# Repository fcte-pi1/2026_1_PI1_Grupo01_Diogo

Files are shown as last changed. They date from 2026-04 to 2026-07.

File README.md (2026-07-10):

# MrBombastic - Grupo 01

Repositório do projeto de um robô autônomo MicroMouse para a disciplina de Projeto Integrador 1 (PI1) da FCTE-UnB.

## Equipe

* **Arthur Guilherme Aquino** - Software
* **Arthur Luiz Silva Guedes** - Eletrônica
* **Enzo Macedo da Motta de Mello** - Estrutura
* **Felipe de Castro Quixabeira** - Eletrônica (Gerente)
* **Fernando de Melo Colli** - Energia (Gerente) e Eletrônica
* **João Igor Pereira da Costa** - Eletrônica e Software
* **Magno Luiz Vale Vieira** - Energia e Software
* **Maria Luisa Alves Rodrigues** - Eletrônica
* **Mariana Pereira Schumann** - Estrutura (Gerente)
* **Matheus de Alcantara da Silva Campos** - Software
* **Raphaela Guimarães de Araujo dos Santos** - Estrutura
* **Renan Pereira Reis** - Software (Gerente)
* **Ricardo Henrique Silva Rodrigues** - Software
* **Tiago Lemes Teixeira** - Gerente Geral
* **Vilmar Jose Fagundes dos Passos Junior** - Estrutura

## Estrutura de Pastas
* **`docs/relatorio/`**: Relatório técnico oficial (LaTeX).
* **`hw/`**: Hardware (esquemáticos e projetos de PCB).
* **`mec/`**: Mecânica (modelagem 3D e CAD).
* **`src/`**: Software (código-fonte e firmware).

---

## Padrões do Repositório

### 1. Nomenclatura de Branches
Padrão: `[ÁREA]_[NÚMERO_DA_ISSUE]-[descrição-curta]`
* **ES** - Estrutura
* **EL** - Eletrônica
* **EN** - Energia
* **SW** - Software
* *Exemplo:* `SW_12-algoritmo-mapeamento`

### 2. Mensagens de Commit
Inicie os commits com os seguintes prefixos:
* **[ADD]**: Criação de arquivos ou funcionalidades.
* **[FIX]**: Correção de bugs.
* **[DOCS]**: Atualização do relatório ou README.
* **[REF]**: Refatoração e organização de código.
* *Exemplo:* `[ADD] leitura dos sensores infravermelhos`

## Guia de Contribuição

### Tutorial: Fluxo Git (Terminal)
Siga este passo a passo para cada nova edição:
1. `git pull origin main` (Atualiza seu local)
2. `git checkout -b [NOME_DA_SUA_BRANCH]` (Cria sua ramificação)
3. Faça suas alterações.
4. `git add .`
5. `git commit -m "[PREFIXO] descrição curta"`
6. `git push origin [NOME_DA_SUA_BRANCH]`
7. Abra o **Pull Request** no site do GitHub.

### Tutorial: Relatório (Sincronização Overleaf)
Como o uso do Overleaf é manual, siga esta ordem:
1. No Overleaf, edite apenas os arquivos na pasta `editaveis/`.
2. Baixe os arquivos `.tex` alterados para sua máquina.
3. Substitua-os na pasta `docs/relatorio/editaveis/` do seu repositório local.
4. Siga o **Fluxo Git** acima para subir as mudanças.
*Observação: Não altere o `main.tex` nem envie arquivos `.pdf` no commit.*

# Como rodar o projeto?

## Rodando o Prisma na Aplicação
Como o Prisma já está configurado no projeto, utilize os comandos abaixo conforme a necessidade.

### 1. Instalar dependências (caso necessário)
```bash
npm install
```

### 2. Gerar o Prisma Client
Sempre que houver alterações no arquivo `schema.prisma`:
```bash
npx prisma generate
```

### 3. Criar uma migration
Após modificar o schema:
```bash
npx prisma migrate dev --name nome_da_migration
```

### 4. Aplicar migrations existentes
Caso esteja clonando o projeto ou atualizando o banco:
```bash
npx prisma migrate deploy
```

### 5. Sincronizar schema sem criar migration
Útil durante desenvolvimento:
```bash
npx prisma db push
```

### 6. Abrir o Prisma Studio
Interface visual para visualizar e editar dados:
```bash
npx prisma studio
```

```bash
npx prisma migrate dev
```
## Rodando o BackEnd
Acessar a pasta do projeto
```bash
cd src/backend
```
Instalar as dependências:
```bash
npm install
```
Executar a plaicação:
```bash
npm run dev
```

## Rodando o FrontEnd
Acessar a pasta do projeto
```bash
cd src/frontend
```
Instalar as dependências:
```bash
npm install
```
Executar a plaicação:
```bash
npm run dev
```

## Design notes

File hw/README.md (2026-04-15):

# _Hardware_

Esta pasta deverá armazenar arquivos referentes a:

- Simulações de circuitos eletrônicos (alimentação, sensores, atuadores etc.): [Qucs](https://qucs.sourceforge.net/), [QSPICE](https://www.qorvo.com/design-hub/design-tools/interactive/qspice), [Fritzing](https://fritzing.org/), dentre outros.
- Esquemáticos de circuitos: [KiCad](https://www.kicad.org/), Qucs, QSPICE.
- Diagramas de bloco: [Canva](https://www.canva.com/pt_br/), [TikZ](https://tikz.net/).
- _Datasheets_ de componentes eletrônicos, microcontroladores, _shields_ Arduino, motores etc.
- Testes tabelados de circuitos: arquivos CSV, Excel.
- Imagens PNG e JPEG de resultados práticos: fotos de testes reais, gráficos de resultados etc.
- Outros arquivos referentes ao _hardware_ do projeto.

> [!WARNING]
> **Não acrescente código-fonte a esta pasta.** O código desenvolvido para microcontroladores e SOCs ([Arduino](https://www.arduino.cc/), [ESP32](https://www.espressif.com/), [Raspberry Pi](https://www.raspberrypi.com/)) deverá ser armazenado na pasta [src/firmware](https://github.com/fcte-pi1/template/tree/main/src/firmware) deste repositório.

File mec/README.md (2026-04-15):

# _Mecânica e Estruturas_

Esta pasta deverá ser utilizada para armazenar arquivos relativos ao projeto estrutural, mecanismos, materiais, estudos aerodinâmicos, equações dinâmicas, construção e manufatura, impressão 3D, e correlatos.

Os arquivos a serem incluídos, são, dentre outros:
- Arquivos CAD de peças e montagens (FCStd, STEP, etc). 
- Desenhos técnicos (pdf, etc).
- Arquivos de impressão 3D (STL, etc).
- Imagens rasterizadas e vetorizadas (eps, pdf, svg, etc).
- Documentos e estudos realizados para o projeto (markdown, LaTeX, etc).

Durante o projeto, os grupos são encorajados a realizarem estudos para o projeto de estruturas, mecanismos, aerodinamica, dentre outros, e muitos desses estudos não caberão no relatório a ser entregue. Esses estudos podem ser colocados também nessa pasta, preferencialmente utilizando markdown (.md) para facilitar a leitura em ambiente web. Lembre-se que você pode utilizar equações em formato LaTeX no markdown e não deixe de utilizar links para o material de referencia que utilizaram. Estudos bem realizados contarão de maneira positiva na avaliação das equipes, porém lembre-se que não é permitida a utilização de IA, e que esse material deve ser principalmente útil à equipe.

> [!WARNING]
> Não acrecente arquivos da parte de hardware eletrônico aqui, como arquivos de KiCAD. Estes devem ser salvos na pasta [hw](https://github.com/fcte-pi1/template/tree/main/hw) deste repositório.

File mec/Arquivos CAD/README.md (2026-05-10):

# Arquivos CAD - MrBombastic

Esta pasta contém os arquivos CAD referentes ao projeto.

## Equipe

Os integrantes envolvidos na criação dos arquivos em CAD foram:

- **Enzo Macedo da Motta de Mello** 
- **Mariana Pereira Schumann**

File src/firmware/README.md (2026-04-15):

# _Firmware_
Esta pasta deverá armazenar arquivos referentes a:

- Código-fonte para microcontroladores e SOCs: [Arduino](https://www.arduino.cc/), [ESP32](https://www.espressif.com/), [Raspberry Pi](https://www.raspberrypi.com/), dentre outros.
- Projetos de organização destes códigos, caso utilize IDEs: [Arduino IDE](https://www.arduino.cc/en/software/), [Visual Studio](https://visualstudio.microsoft.com/pt-br/downloads/) etc.
- Arquivos de configuração: ```CMakeLists.txt``` se for usar [CMake](https://cmake.org/download/), ```Makefile``` se for usar [make](https://www.cs.colby.edu/maxwell/courses/tutorials/maketutor/) etc.

Evite incluir:
- Artefatos de compilação: os arquivos de saída compilados (binários, arquivos objeto, .hex, .elf) devem ser gerados pelo processo de compilação e não incluídos no repositório.
- Arquivos temporários/específicos do sistema operacional: Arquivos como .DS_Store (macOS) ou arquivos de configuração do editor (a menos que esteja usando uma configuração compartilhada como .editorconfig).
- Configurações pessoais: Arquivos de configuração locais específicos da máquina do desenvolvedor.

> [!WARNING]
> **Não acrescente arquivos referentes a _hardware_ nesta pasta.** Eles deverão ser armazenados na pasta [hw](https://github.com/fcte-pi1/template/tree/main/hw) deste repositório.

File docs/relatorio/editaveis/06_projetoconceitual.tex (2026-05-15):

\chapter{Projeto Conceitual do Produto}

\section{Características gerais}

O produto proposto é um robô autônomo de pequeno porte, denominado Micromouse, cujo objetivo
principal é explorar e resolver labirintos desconhecidos de forma completamente autônoma, sem
qualquer intervenção humana durante o percurso. O robô deverá ser capaz de mapear o ambiente,
monitorar sua própria localização, detectar paredes com $5{,}0\,\text{cm}$ de altura e
$1{,}2\,\text{cm}$ de espessura, e identificar quando alcançou a região central do labirinto,
que corresponde a uma sala retangular de aproximadamente $2 \times 2$ células.

O Micromouse será construído dentro das dimensões máximas de
$25{,}0\,\text{cm} \times 25{,}0\,\text{cm}$, sobre um \textit{chassis} com tração diferencial
de duas rodas motorizadas e uma roda de apoio livre. A navegação será realizada por meio de
três sensores de distância por tempo de voo (\textit{Time of Flight}) VL53L0X, posicionados
nas direções frontal e laterais, complementados por uma unidade de medição inercial MPU6050
responsável pela correção de trajetória nas curvas. O controle dos motores N20 será feito por
uma ponte H TB6612FNG, além disso, eles já apresentam encoder acoplados a cada motor.

O sistema embarcado será gerenciado por um microcontrolador ESP32 DevKitV1, responsável pela
execução do algoritmo de navegação, pelo mapeamento do labirinto em memória e pela comunicação
sem fio via Wi-Fi com a interface de telemetria. O produto contará com monitoramento em tempo
real de tensão e corrente por meio do módulo INA219, exibindo na tela de acompanhamento o tipo
do labirinto, o trajeto percorrido, a velocidade média, o consumo de bateria e o tempo de
conclusão. A alimentação será fornecida por duas células de lítio Lishen LR2170SA em
configuração $2S$, gerenciadas por um BMS 2S 20A com indicador de carga, e reguladas por um
conversor Buck DC-DC para $5{,}0\,\text{V}$.

Para garantir a viabilidade e a qualidade das entregas, foi elaborada uma Estrutura Analítica
do Projeto (EAP), que pode ser visualizada na Figura~\ref{fig:eap}.

\begin{landscape}
    \begin{figure}[htbp]
        \centering
        \includesvg[width=1\linewidth]{figuras/EAP}
        \caption{Estrutura Analítica do Projeto}
        \label{fig:eap}
    \end{figure}
\end{landscape}

\section{Estrutura}

\subsection{Introdução}
Esta seção reúne as análises e decisões referentes ao planejamento estrutural e mecânico do Micromouse. Inclui o desenho do chassi, a definição dos materiais, a organização interna do esqueleto e a escolha do sistema de locomoção, seja bimotor ou com soluções de tração mais complexas. Abrange também a especificação dos motores que garantirão mobilidade adequada e a análise de componentes adicionais, como ventoinhas voltadas à estabilidade.

Além disso, contempla a metodologia utilizada para o desenvolvimento do labirinto de testes, seguindo rigorosamente o padrão oficial de dimensões e acabamento, permitindo a validação realista do desempenho do robô.

\subsection{Modelos CAD da Estrutura}
Abaixo, estão apresentadas, em CAD e desenvolvidas no SolidWorks, as imagens do chassi do micromouse, de sua montagem com os componentes, além dos pinos, paredes e piso do labirinto de testes. As paredes, os pinos e o chassi serão fabricados por impressão 3D, enquanto o piso do labirinto será confeccionado em MDF.

Os modelos CAD podem ser observados na Figura~\ref{fig:CADs}

\begin{figure}[H]
    \centering
    
    \begin{subfigure}[b]{0.40\textwidth}
        \centering
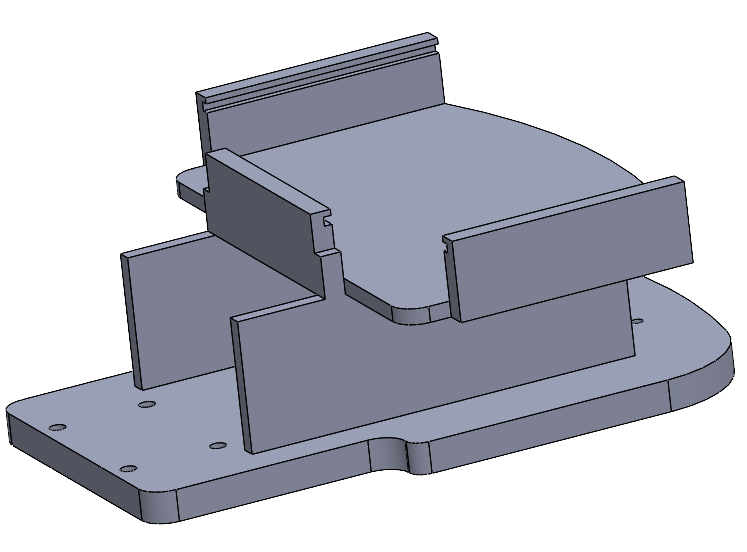
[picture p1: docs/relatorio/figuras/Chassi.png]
        
        \caption{Chassi do micromouse}
        \label{fig:CadChassi}
    \end{subfigure}
    \hfill 
    \begin{subfigure}[b]{0.40\textwidth}
        \centering
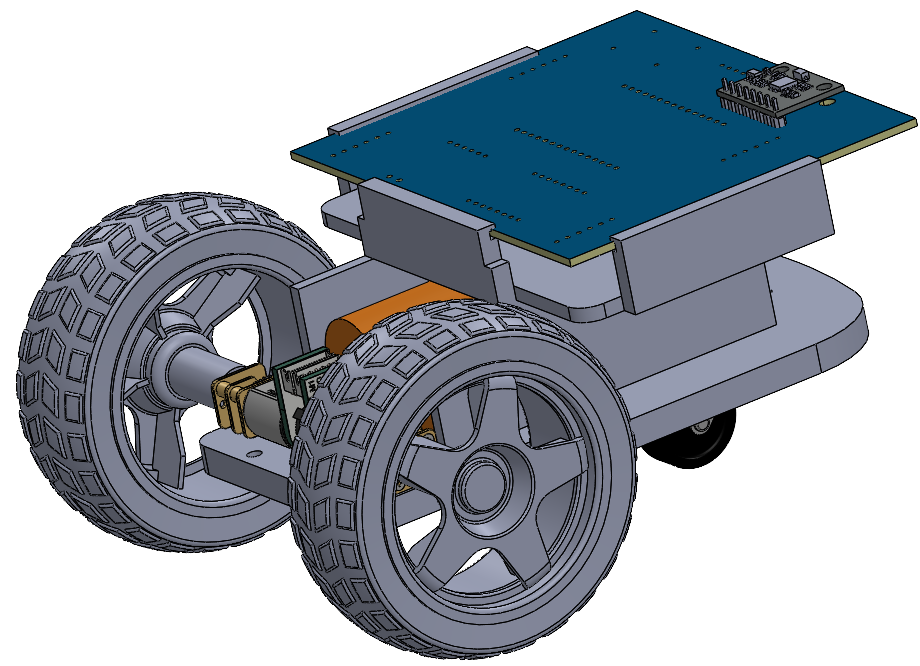
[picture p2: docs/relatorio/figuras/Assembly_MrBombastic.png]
        
        \caption{Assembly do micromouse}
        \label{fig:AssemblyMrBombastic}
    \end{subfigure}
    
    \begin{subfigure}[b]{0.40\textwidth}
        \centering
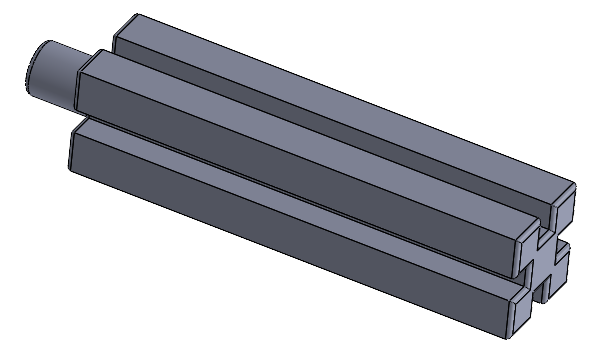
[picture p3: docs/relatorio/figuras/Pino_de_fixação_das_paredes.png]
        
        \caption{Pinos de fixação das paredes}
        \label{fig:CadPinos}
    \end{subfigure}
    \hfill
    \begin{subfigure}[b]{0.40\textwidth}
        \centering
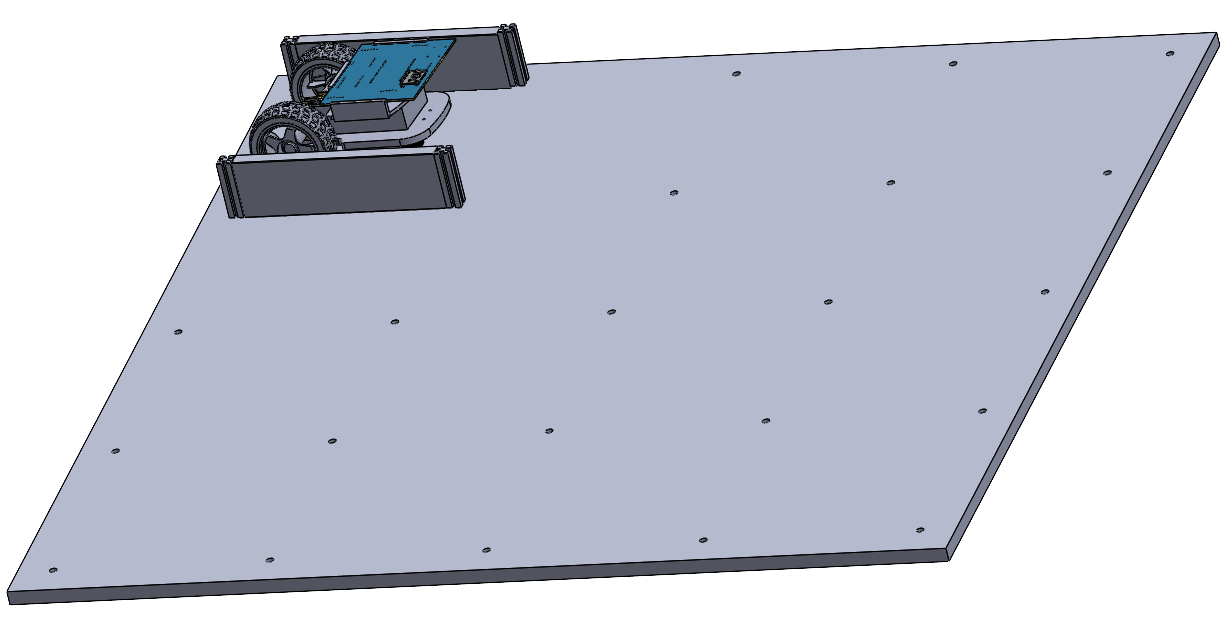
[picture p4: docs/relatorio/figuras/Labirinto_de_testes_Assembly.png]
        
        \caption{Montagem do labirinto}
        \label{fig:AssemblyLabirinto}
    \end{subfigure}
    
    \caption{CADs do projeto}
    \label{fig:CADs}
\end{figure}

Na tabela a seguir, estão descritas as dimensões dos desenhos em CAD, com suas respectivas alturas, comprimentos e larguras.

\begin{table}[H]
    \centering
    \caption{Dimensões das peças}
    \label{tab:dimensoes_pecas}
    \begin{tabular}{|c|c|c|c|}
        \hline
        \textbf{Item} & \textbf{Comprimento [mm]} & \textbf{Altura [mm]} & \textbf{Largura [mm]} \\ \hline
        (a) &120,21 &46,35 &105 \\ \hline
        (b) &146,93 &68,55 &121,92 \\ \hline
        (c) &12 &12 &57 \\ \hline
        (d) &780 &12 &780 \\ \hline
    \end{tabular}
\end{table}

\subsection{Decisões do projeto}

\subsubsection{Planejamento do Chassi}
O chassi do micromouse será desenvolvido baseado ao Projeto Jabuti \cite{Projeto_Jabuti} com o uso da impressora 3D, usando como material, o \textbf{filamento PLA} para sua construção. No projeto do chassi, a bateria foi posicionada próxima ao centroide da estrutura por ser o componente de maior massa do sistema. Essa configuração contribui para uma melhor distribuição de peso, garantindo maior estabilidade durante o movimento e reduzindo a necessidade de adicionar massas extras para balanceamento do micromouse. Além disso, o posicionamento central auxilia na diminuição da tendência de inclinação durante curvas, melhorando o desempenho dinâmico do micromouse.

\subsubsubsection{Justificativa para a escolha da \textbf{impressora 3D}}
As principais vantagens de usar a impressora 3D para a construção do chassi do micromouse são:

\begin{enumerate}
    \item \textbf{Liberdade Absoluta para Posicionamento de Sensores:} Trazendo a possibilidade de desenhar suportes inclinados e embutidos para os sensores de distância.
    
    \item \textbf{Prototipagem Rápida e Design Iterativo:} A impressão 3D permite ajustar o CAD e fabricar uma nova base em poucas horas, acelerando o ciclo de desenvolvimento.
    
    \item \textbf{Otimização de Peso e Customização Estrutural:} A impressão 3D permite controlar a densidade interna da peça. Ajustando o preenchimento. Logo, o chassi torna-se extremamente leve, permitindo reforços estruturais apenas nos pontos de maior estresse físico.

    \item \textbf{Facilidade:} Tendo em vista que um dos integrantes possui a impressora 3D, torna mais fácil fazer as alterações necessárias do chassi do micromouse.
\end{enumerate}

\subsubsection{Sistema de Locomoção}
Para o sistema de locomoção será utilizado 3 rodas, uma ao centro do micromouse para sustentação e as outras duas para movimentação e curvas nas laterais traseiras do carrinho. A escolha do conjunto de rodas baseou-se em critérios de confiabilidade técnica, integração estrutural e eficiência em simetria com a pista de testes. As especificações das rodas são as seguintes:

\begin{table}[htbp]
    \centering
    \caption{Rodas de movimentação}
    \label{tab:placeholder}
    \begin{tabular}{|c|c|} \hline
        Diâmetro & 68mm \\ \hline
        Largura & 26mm \\ \hline
        Furo central & 5,3mm x 3,66mm (Semicírculo) \\ \hline
        Peso & 50g \\ \hline
    \end{tabular}
\end{table}

\begin{table}[htbp]
    \centering
    \caption{Roda de sustentação}
    \label{tab:placeholder}
    \begin{tabular}{|c|c|} \hline
        Diâmetro & 19mm \\ \hline
        Largura & 7,9mm \\ \hline
        Furo central & $\varnothing$ 2,36mm \\ \hline
    \end{tabular}
\end{table}

\subsubsection{Labirinto de Testes}
A construção do labirinto de testes foi baseada na estrutura feita pela UKMARS (Sociedade Britânica de Micromouse e Robótica) \cite{ukmars_maze}. Para o piso, será utilizado o material \textbf{MDF (\textit{Medium-Density Fiberboard})}, enquanto as paredes e pinos de sustentação serão confeccionados em \textbf{impressora 3D}. O labirinto de testes foi desenvolvido de forma que permitisse a alteração da posição das paredes, possibilitando diferentes configurações de percurso. Dessa maneira, torna-se possível realizar testes em variados cenários, ampliando as possibilidades de validação do funcionamento do micromouse e permitindo a análise de seu desempenho em trajetórias com diferentes níveis de complexidade.

\subsubsubsection{Justificativa da Escolha do MDF para o piso}
As principais vantagens de utilizar o \textbf{MDF} são: 

\begin{enumerate}
    \item \textbf{Superfície Lisa e Sem Veios:} Ao contrário da madeira compensada ou maciça, o MDF não possui ``veios'', nós ou irregularidades naturais. Isso é fundamental para a Odometria Precisa e a Leitura de Sensores do Micromouse.
    
    \item \textbf{Excelente Acabamento para Pintura:} O piso do labirinto de Micromouse precisa ser pintado de preto para criar alto contraste. O MDF absorve muito bem as tintas, permitindo um acabamento liso e sem reflexos, o que é crucial para que a luz ambiente ou os emissores do robô não causem leituras erradas nos sensores de parede.
    
    \item \textbf{Alta Precisão de Corte e Usinagem:} Devido as células do labirinto terem um padrão de medidas muito rígidas ($18\,\text{cm} \times 18\,\text{cm}$). O MDF é extremamente fácil de cortar com serras circulares ou máquinas de corte a laser/CNC sem lascar as bordas. 
    
    \item \textbf{Estabilidade Dimensional (em ambientes internos):} Desde que mantido longe de umidade, o MDF é muito mais estável que a madeira comum. Ele não empena ou torce facilmente com variações normais de temperatura, garantindo que o seu piso fique perfeitamente nivelado. Um piso desnivelado pode fazer o robô raspar o chassi ou perder a calibração do giroscópio.
    
    \item \textbf{Custo-Benefício:} Construir o piso com materiais como acrílico fosco, polímeros de engenharia ou metais seria financeiramente inviável para o projeto. O MDF oferece um equilíbrio perfeito entre qualidade profissional e preço acessível.    
\end{enumerate}

\subsubsubsection{Justificativa da Escolha da impressora 3D}
As principais vantagens de utilizar a \textbf{Impressora 3D} são:

\begin{enumerate}
    \item \textbf{Cores Nativas:} Com a impressora 3D, pode-se simplesmente usar filamento branco para a parede e usar filamento vermelho para o topo. Isso economiza horas de isolamento com fita crepe, aplicação de primer e secagem de tinta, além de evitar o risco da tinta descascar com as batidas do robô.
    
    \item \textbf{Design de Encaixe Perfeito (Tolerâncias Customizadas):} É possível modelar os pinos com tolerâncias exatas para o diâmetro dos furos que serão feitos no MDF e para a espessura das paredes.
    
    \item \textbf{Reprodutibilidade e Precisão Dimensional:} O labirinto exige dezenas de paredes e pinos idênticos. A impressora 3D garante que a parede número 1 terá exatamente as mesmas dimensões da parede número 80. Diferente de cortar madeira ou acrílico manualmente, onde erros milimétricos se acumulam e estragam o \textit{grid} da pista, a impressora entrega consistência.
    
    \item \textbf{Baixo Peso com Boa Resistência:} Filamentos comuns como PLA ou PETG são mais do que resistentes o suficiente para aguentar os impactos de um Micromouse.
    
    \item \textbf{Facilidade:} Tendo em vista que um dos integrantes possui a impressora 3D, torna mais fácil fazer as alterações necessárias e ajustes das paredes e pinos do labirinto.
\end{enumerate}

% ============================================================
% SEÇÃO 4.3 — DESCRIÇÃO DE HARDWARE (ATUALIZADA)
% ============================================================
\section{Descrição de \textit{hardware}}

O \textit{hardware} proposto para o sistema foi projetado a partir de uma arquitetura modular
para um robô móvel autônomo, com foco em processamento eficiente, sensoriamento preciso e
monitoramento energético. A arquitetura é organizada em quatro módulos principais:
\textbf{Processamento}, \textbf{Sensoriamento}, \textbf{Atuação} e \textbf{Gerenciamento de
Energia}. A organização sistêmica entre esses módulos pode ser visualizada no diagrama de
blocos da Figura~\ref{fig:diag.blocos}, enquanto as conexões elétricas detalhadas entre os
componentes são apresentadas nos esquemáticos das Figuras~\ref{fig:esque.princi}
e~\ref{fig:esque.bms}.

Toda a eletrônica do sistema será montada sobre \textbf{placa perfurada} (\textit{perfboard}),
permitindo a integração compacta dos componentes de forma modular, reutilizável e de custo
reduzido, sem a necessidade de fabricação de uma \textit{Printed Circuit Board} (PCB) dedicada
nesta fase do projeto.

\begin{figure}[H]
    \centering
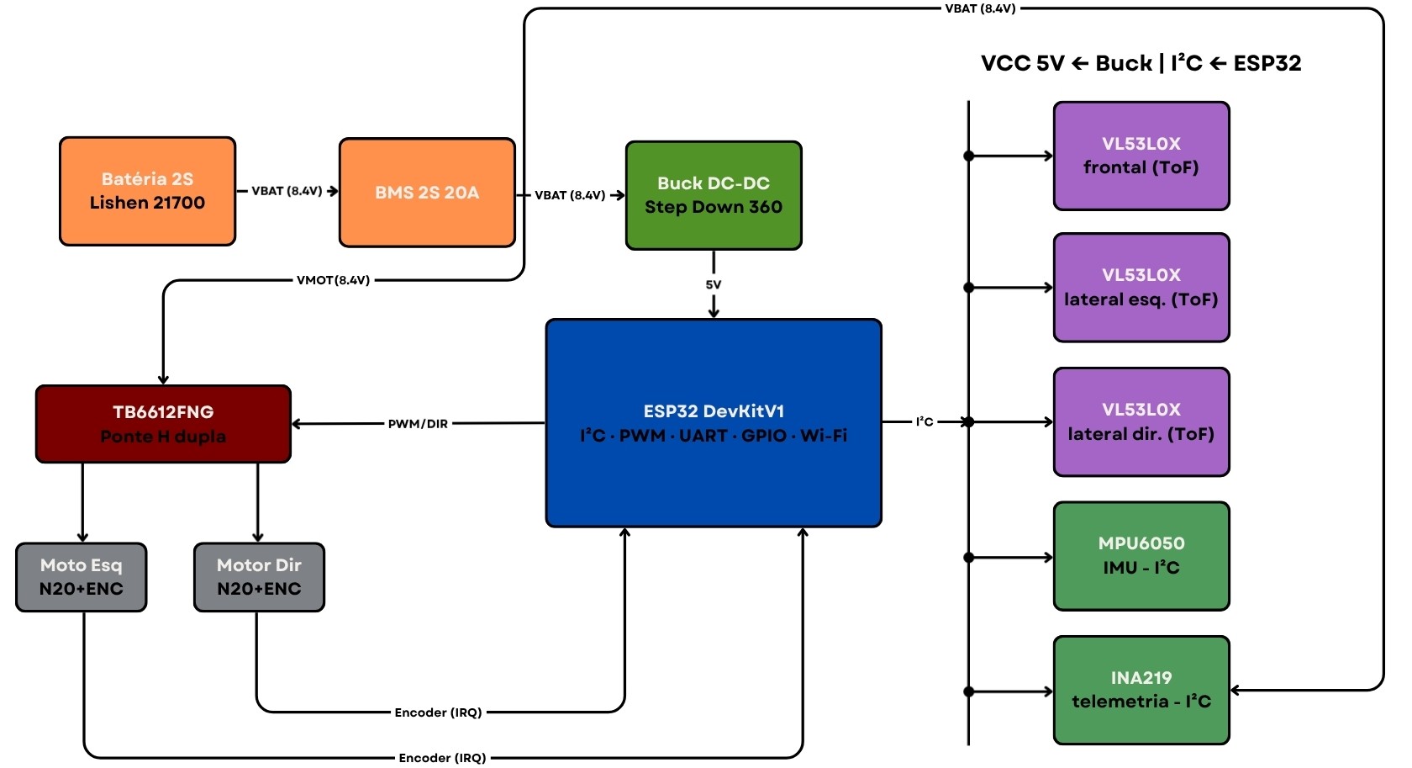
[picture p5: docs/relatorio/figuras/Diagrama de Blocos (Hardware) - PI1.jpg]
    
    \caption{Diagrama de Blocos}
    \label{fig:diag.blocos}
\end{figure}

\begin{figure}[H]
    \centering
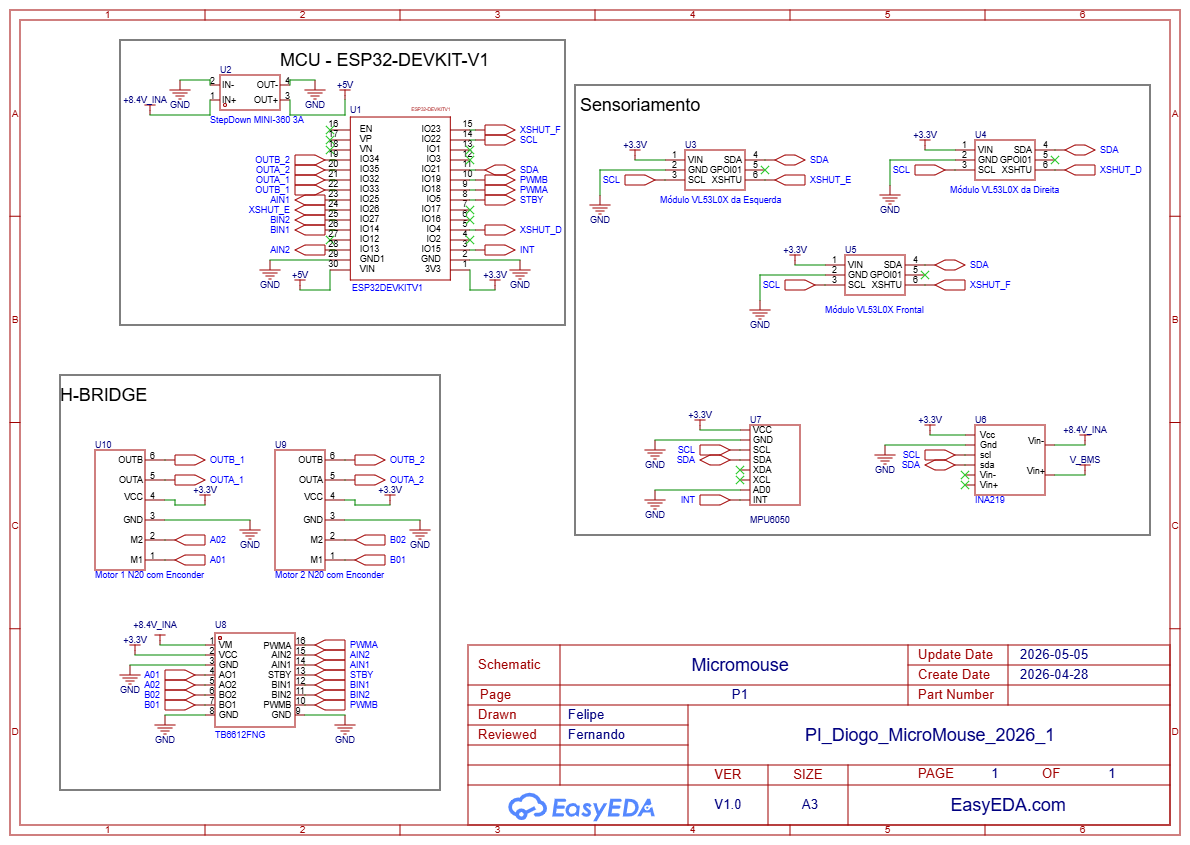
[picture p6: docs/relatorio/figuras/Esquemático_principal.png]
    
    \caption{Esquemático Principal do Hardware}
    \label{fig:esque.princi}
\end{figure}

\begin{figure}[H]
    \centering
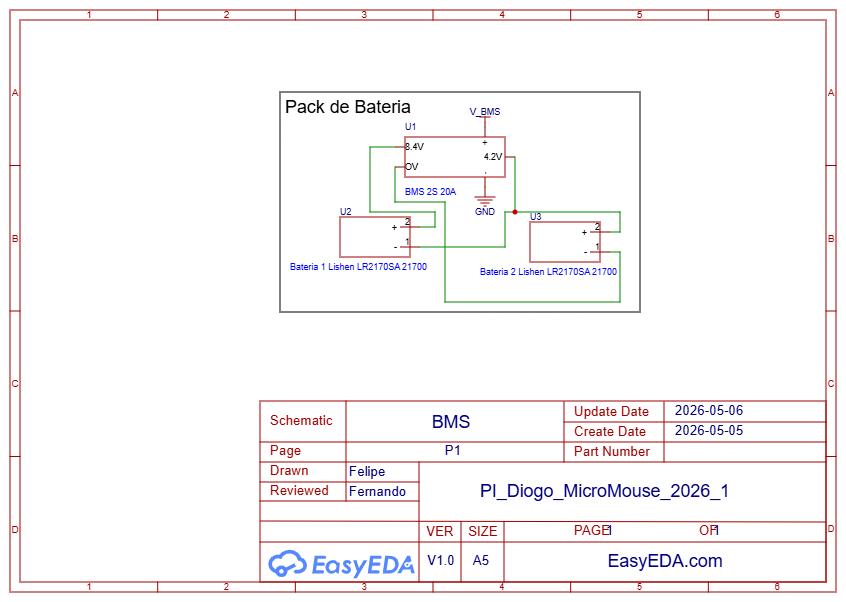
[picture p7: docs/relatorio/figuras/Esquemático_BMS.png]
    
    \caption{Esquemático do pack de baterias}
    \label{fig:esque.bms}
\end{figure}

\subsection{Módulo de Processamento}

O núcleo do sistema é o microcontrolador \textbf{ESP32 DevKitV1}, baseado no SoC ESP32 da
Espressif Systems. Sua escolha se justifica pela necessidade de processar dados provenientes
de múltiplos sensores no barramento $I^2C$ em tempo real, executar o algoritmo de navegação e
mapeamento do labirinto em memória, além de realizar comunicação sem fio via \textit{Wi-Fi}
para telemetria. O ESP32 opera com clock de até 240\,MHz com dois núcleos, possui 520\,KB de
RAM e 4\,MB de Flash, e suporta nativamente os protocolos $I^2C$, UART, SPI e PWM, todos
utilizados neste projeto. A programação é realizada via USB utilizando a Arduino IDE com o
\textit{core} ESP32 da Espressif.

\subsection{Módulo de Sensoriamento}

\subsubsection{Sensores de Distância VL53L0X}

O sensor \textbf{VL53L0X} é um módulo de distância por \textit{Time of Flight} (ToF) fabricado
pela STMicroelectronics. Diferentemente de sensores infravermelhos analógicos, o VL53L0X emite
pulsos de luz laser infravermelha (850\,nm) e mede o tempo de retorno para calcular a distância
com precisão de até 1\,mm e alcance de até 2\,m em condições ideais. No contexto do Micromouse,
onde as paredes do labirinto distam entre 0 e 18\,cm, este sensor oferece excelente resolução
e imunidade a variações de cor e refletividade da superfície.

Serão utilizados três módulos VL53L0X: um posicionado na frente do robô (Frontal) e
dois nas laterais (Esquerda e Direita), possibilitando a detecção de paredes em todas as
direções relevantes à navegação. Todos os sensores compartilham o barramento $I^2C$ com o
ESP32. Para que dispositivos com o mesmo endereço padrão possam coexistir no barramento, cada
sensor possui um pino \texttt{XSHUT} conectado a uma GPIO do ESP32, permitindo que cada
unidade seja inicializada individualmente e tenha seu endereço $I^2C$ reconfigurado por
software antes de ser liberada para operação.

\subsubsection{Unidade de Medição Inercial MPU6050}

O \textbf{MPU6050} é uma IMU (\textit{Inertial Measurement Unit}) de 6 eixos, combinando
acelerômetro e giroscópio em um único encapsulamento com interface $I^2C$. No sistema, ele é
responsável pela estimativa da orientação angular (\textit{heading}) do robô durante as curvas,
complementando os dados dos sensores ToF e dos encoders. O giroscópio fornece a taxa de rotação
em torno do eixo Z (yaw), permitindo ao algoritmo de controle corrigir desvios angulares e
garantir que as curvas de 90° sejam executadas com precisão.

\subsubsection{Sensor de Corrente e Tensão INA219}

O \textbf{INA219} é um sensor de corrente e tensão bidirecional da Texas Instruments com
interface $I^2C$. Ele é inserido em série no barramento de alimentação do sistema e realiza a
medição da tensão na carga e da corrente consumida por meio de um resistor \textit{shunt} de
precisão (0,1\,$\Omega$). Com resolução de 12 bits e faixa de medição de até 3,2\,A e 32\,V,
o INA219 permite o monitoramento contínuo do consumo energético em tempo real. Os dados
coletados são utilizados pelo firmware para calcular a potência instantânea, estimar a
autonomia restante da bateria e acionar alertas de subtensão, sendo também transmitidos via
\textit{Wi-Fi} para o painel de telemetria.

\subsubsection{Encoders dos Motores}

Os motores N20 selecionados já possuem encoders magnéticos acoplados ao eixo traseiro.
Cada encoder gera pulsos por interrupção nas GPIOs do ESP32, permitindo o cálculo da velocidade
de rotação (RPM) e do deslocamento linear percorrido por cada roda. Esses dados são fundamentais
para a implementação do controle PID de velocidade e para a odometria, possibilitando que o
robô estime sua posição relativa dentro do labirinto.

\subsection{Módulo de Atuação}

\subsubsection{Motores N20 com Redução}

Os atuadores de locomoção são dois motores \textbf{DC N20} com caixa de redução, escolhidos
pelo seu tamanho compacto, baixo peso e torque adequado para a massa estimada do robô. Cada
motor é controlado individualmente por um canal do driver TB6612FNG, recebendo sinais de
direção e PWM provenientes do ESP32.

\subsubsection{Driver de Motor TB6612FNG}

O \textbf{TB6612FNG} é um driver de ponte H dupla da Toshiba capaz de acionar dois motores DC
de forma independente. Opera com tensão de motor de até 15\,V e corrente contínua de 1,2\,A
por canal, suportando picos de 3,2\,A. O controle de direção é feito pelos pinos
\texttt{AIN1}/\texttt{AIN2} e \texttt{BIN1}/\texttt{BIN2}, enquanto a velocidade é modulada
pelos pinos \texttt{PWMA} e \texttt{PWMB} via sinal PWM gerado pelo ESP32. O pino \texttt{STBY}
deve ser mantido em nível alto para habilitar a operação do \textit{chip}.

\subsection{Módulo de Gerenciamento de Energia}

A alimentação do sistema é fornecida por duas células de lítio-íon \textbf{Lishen LR2170SA
(21700)} em configuração 2S1P, totalizando 4000\,mAh e tensão nominal de 7,4\,V (8,4\,V
carregadas). Um \textbf{BMS 2S 20A} (modelo HW-391) é responsável pela proteção contra
sobrecarga, subdescarga e curto-circuito, além de realizar o balanceamento das células durante
a carga. Para a alimentação da lógica, um conversor \textbf{Buck DC-DC Step Down 360} regula
a tensão de entrada para 5\,V estáveis, que alimentam o ESP32 pelo pino \texttt{VIN}. Os
motores são alimentados diretamente pelo barramento de bateria (7,4\,V -- 8,4\,V). O
esquemático do pack de baterias com a BMS é apresentado na Figura~\ref{fig:esque.bms}.

\begin{comment}
\textcolor{red}{A descrição de \textit{hardware} no documento deve permitir que outras pessoas repliquem o produto proposto neste documento. Para isso, deve-se explicar de forma textual os principais sub-sistemas e as escolhas de projeto, além de indicar:}

\begin{itemize}
    \item \textcolor{red}{ O diagrama de blocos \cite{blockdiagram}, que oferece uma visão geral do hardware, com as principais partes do sistema e as ligações entre elas.}
    %\item A lista de materiais \cite{bom}, que facilita a montagem do sistema, indicando tudo que deve ser adquirido. Aproveitem a lista de materiais para apresentarem o orçamento dos mesmos.
    \item \textcolor{red}{ O esquemático \cite{esquematico}, que mostra as conexões elétricas entre os componentes. Deve-se indicar os componentes por nomes e símbolos, e as conexões entre eles, incluindo a pinagem dos componentes. Se o esquemático ficar muito grande, pode-se separa-lo em vários esquemáticos. A ligação em \textit{protoboard} não é considerada um esquemático adequado.}
\end{itemize}

\textcolor{red}{A Fig. \ref{fig:diagrama_blocos_e_esquematico} apresenta o diagrama de blocos e o esquemático de um circuito conversor de corrente alternada para corrente direta, a título de exemplo. Repare que o diagrama de blocos indica os sub-sistemas do circuito completo apresentado no esquemático. 
% Comecem com o diagrama de blocos, que é mais genérico, e depois indiquem os detalhes com a lista de materiais e os esquemáticos.
}

\begin{figure}
    \centering
    
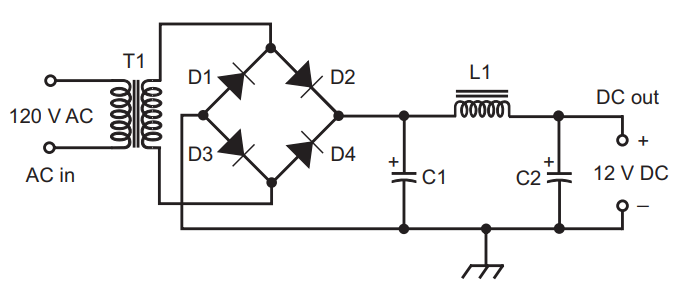
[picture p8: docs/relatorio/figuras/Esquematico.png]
    
    \caption{\textcolor{red}{Diagrama de blocos e esquemático de um circuito conversor de corrente alternada para corrente direta. Extraído de \cite{block_n_schematic}.}}
    \label{fig:diagrama_blocos_e_esquematico}
\end{figure}
\end{comment}

\section{Análise de Consumo Energético}

A análise de consumo energético do micromouse é fundamental para garantir a autonomia necessária durante a execução dos desafios propostos, assegurando estabilidade operacional e prevenindo quedas de tensão que possam comprometer a navegação. Nesta seção, detalham-se os subsistemas elétricos, os cálculos de consumo individual e total, a seleção da fonte de alimentação e os mecanismos de regulação e monitoramento.

\subsection{Identificação dos Subsistemas Elétricos}

Os componentes foram classificados de acordo com sua função no sistema e caracterizados pela tensão de operação, corrente média consumida e tempo aproximado de uso durante um ciclo típico de execução de dez minutos. A configuração final inclui três sensores de distância por tempo de voo (ToF) e uma unidade de medição inercial (IMU) para controle de orientação. A Tabela~\ref{tab:subsistemas_consumo} apresenta os valores consolidados.

\begin{table}[htbp]
\centering
\caption{Caracterização dos subsistemas elétricos do micromouse.}
\label{tab:subsistemas_consumo}
\resizebox{\columnwidth}{!}{%
\begin{tabular}{|l|l|c|c|c|}
\hline
\textbf{Componentes} & \textbf{Subsistema} & \textbf{Tensão (V)} & \textbf{Corrente (mA)} & \textbf{Tempo (s)} \\ \hline
ESP32 DevKit & Processamento & 3,3 & 150 & 600 \\ \hline
2x Motores N20 + TB6612FNG & Atuadores & 7,4 -- 8,4 & 500 & 400 \\ \hline
3x VL53L0X + MPU6050 + Encoders & Sensoriamento & 3,3 & 66 & 600 \\ \hline
INA219 & Telemetria & 3,3 & 1 & 600 \\ \hline
\end{tabular}%
}
\end{table}

\subsection{Cálculo da Energia Consumida por Componente}

A energia demandada por cada subsistema foi calculada utilizando a fórmula $E = V \cdot I \cdot t$, onde $E$ corresponde à energia consumida em joules (J), $V$ é a tensão nominal, $I$ a corrente média em ampères e $t$ o tempo de operação em segundos:

\begin{itemize}
    \item \textbf{Processamento (ESP32):} $3,3 \times 0,150 \times 600 = 297\,\mathrm{J}$
    \item \textbf{Atuadores (Motores e Driver):} $7,4 \times 0,500 \times 400 = 1480\,\mathrm{J}$
    \item \textbf{Sensores e Telemetria:} $3,3 \times 0,067 \times 600 \approx 132,7\,\mathrm{J}$
\end{itemize}

\subsection{Estimativa do Consumo Total de Energia}

Somando as demandas individuais, o consumo total estimado para um ciclo de operação é:

\[
E_{\mathrm{total}} = 1909,7\,\mathrm{J}
\]

Este valor reflete a demanda energética considerando a carga total do hardware embarcado em regime contínuo.

\subsection{Escolha da Fonte de Alimentação}

Para a seleção da bateria, converte-se o consumo total de Joules para Watt-hora (Wh), conforme a relação $1\,\mathrm{Wh} = 3600\,\mathrm{J}$:

\[
E_{\mathrm{Wh}} = \frac{1909,7}{3600} \approx 0,530\,\mathrm{Wh}
\]

A fonte selecionada consiste em um pack de baterias de Lítio-Íon Lishen LR2170SA (21700) em configuração 2S1P, totalizando 4000 mAh e energia nominal de aproximadamente $29,2\,\mathrm{Wh}$.

\textbf{Margem de Segurança:} Adotou-se uma margem de segurança de 30\%, padrão para compensar picos de corrente em acelerações bruscas e evitar a descarga profunda. Mesmo com este critério, a bateria selecionada excede a demanda de um ciclo operacional em mais de 50 vezes, garantindo estabilidade e múltiplas execuções sem recarga.

\subsection{Monitoramento via Software}

O monitoramento energético é realizado através do sensor INA219 via barramento $I^2C$. O software embarcado executa as seguintes rotinas:
\begin{itemize}
    \item \textbf{Telemetria:} Registro da tensão e tempo de operação, com envio de pacotes JSON a cada 50 ms via UART/Wi-Fi.
    \item \textbf{Segurança:} Rotina de interrupção que monitora se a tensão por célula atinge $3,2\,\mathrm{V}$, permitindo uma parada segura antes do corte automático da BMS.
\end{itemize}

\subsection{Plano de Validação e Testes Reais}

\begin{itemize}
    \item \textbf{Nota de Revisão:} Esta secção descreve a metodologia de validação a ser executada durante o PC2. Os dados teóricos aqui apresentados deverão ser substituídos pelos valores experimentais após a realização dos testes de campo.
\end{itemize}

A validação do sistema energético consistirá na comparação entre o consumo teórico calculado ($1909,7\,\mathrm{J}$) e os dados reais recolhidos via telemetria durante ciclos de operação no labirinto. O procedimento de teste seguirá as etapas:

\begin{itemize}
    \item \textbf{Monitorização em Tempo Real:} Utilização do sensor INA219 para registar a queda de tensão e o consumo de corrente em diferentes perfis de movimento (aceleração, curvas e velocidade constante).
    \item \textbf{Análise de Descarga:} Confronto dos dados obtidos com a curva de descarga nominal das células Lishen LR2170SA para verificar a precisão da estimativa de autonomia.
    \item \textbf{Justificativa de Desvios:} Eventuais divergências entre os resultados teóricos e práticos serão analisadas considerando perdas térmicas por efeito Joule no cabeamento e a eficiência real dos reguladores Buck DC-DC sob carga.
\end{itemize}

Os resultados finais desta validação permitirão o refinamento dos algoritmos de segurança e a calibração final dos alertas de subtensão no software embarcado.

\subsection{Planejamento do Circuito de Alimentação}

A arquitetura de alimentação foi projetada para garantir eficiência e proteção das células:
\begin{itemize}
    \item \textbf{Regulação:} A bateria alimenta diretamente os atuadores, enquanto um conversor buck DC-DC fornece 5 V estáveis ao microcontrolador pelo pino Vin.
    \item \textbf{Proteção:} Uma BMS 2S 20A (modelo HW-391) monitora limites de tensão e corrente, contando com função de balanceamento para equalização das células durante a carga. O corte de descarga (overdischarge) é configurado tipicamente em 2,5 V (faixa de 2,4 V a 2,6 V).
    \item \textbf{Isolamento de Ruído:} O uso do conversor buck isola a lógica de controle das flutuações geradas pelos motores.
    \item \textbf{Diretriz de Montagem:} É obrigatório o uso de solda-ponto para evitar danos térmicos às vedações das baterias.
\end{itemize}

\section{Descrição de \textit{software}}

\subsection{Diagrama de Atividades UML}

O diagrama de atividades UML apresentado indica o funcionamento do robô Micromouse em seu curso de navegação em um labirinto. Este fluxo está organizado em raias, que separam as responsabilidades entre sensores, processador central e atuadores. 

Para iniciar a atividade, os sensores devem capturar os dados do ambiente do labirinto, como distância e orientação, servindo assim como entradas do sistema. A partir desse momento, o processador central busca realizar o tratamento dessas informações, tomando decisões sobre a movimentação do robô e verificando obstáculos ao definir a melhor rota.

A execução paralela de atividades é demonstrada no diagrama ao atualizar o mapa do labirinto e calcular a correção de trajetória. Com o término do processamento, atuadores executam comandos de movimento físicos que buscam a saída do sistema. Desta forma o robô verifica se alcançou a coordenada estipulada. Caso contrário, o ciclo de navegação é repetido até atingir o objetivo final. O Diagrama de Atividades UML está disponível no seguinte link: \href{https://www.plantuml.com/plantuml/svg/XLNFRXot3xxFKn3uNUoJVqqAj7LWDDkr9t3XTGDlqbCkz8WxoqGZBYIDawPR84_GNWhqMgI780LoSli4yoPvab9QxH_NCIfZuH4baXy_Vfnv62Bws7UsYXmjmJ5Zwx5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}{Link do Diagrama de Atividades}.

\begin{figure}[H]
    \centering
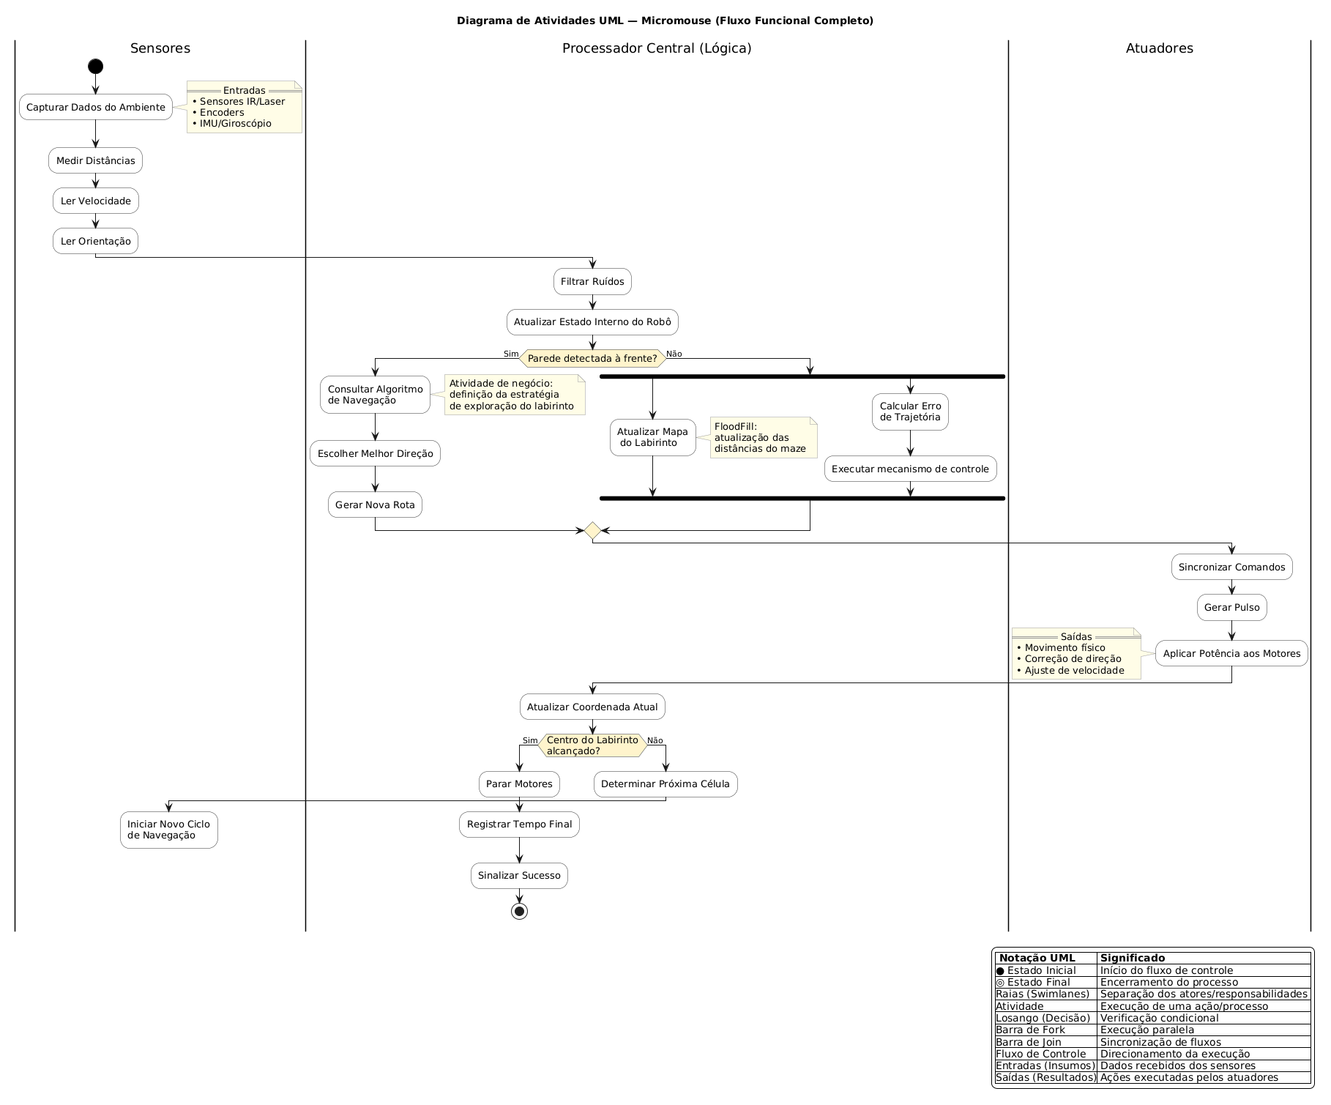
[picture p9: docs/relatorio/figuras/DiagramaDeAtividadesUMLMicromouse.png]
    
    \caption{Diagrama de Atividades UML}
    \label{fig:placeholder}
\end{figure}

\subsection{Backlog do Produto}

O backlog do produto representa a lista priorizada de funcionalidades e requisitos que orientam o desenvolvimento do sistema Micromouse. Sua construção foi realizada a partir das Histórias de Usuário apresentadas na Tabela 5, relacionando os Requisitos Funcionais (RFs) e Não Funcionais (RNFs) definidos para o projeto.

Os Requisitos Não Funcionais foram organizados conforme a técnica URPS+ (Usabilidade, Confiabilidade, Desempenho, Suportabilidade e outros), garantindo que aspectos essenciais como estabilidade, desempenho, experiência do usuário e manutenção do sistema fossem considerados no planejamento.

Cada história de usuário inclui critérios de aceitação, requisitos associados e prioridade classificada segundo o método MoSCoW, categorizando-as em Must Have ou Should Have de acordo com sua relevância para o funcionamento autônomo do micromouse.

\begin{table}[htbp]
\begin{center}
\scriptsize
\setlength{\tabcolsep}{4pt}
\renewcommand{\arraystretch}{1.5} % Ajustado para 1.5 para melhor leitura das células com muito texto
\caption{Backlog de Histórias de Usuário para o Sistema Micromouse.}
\begin{tabular}{|c|p{5cm}|p{4cm}|p{2cm}|p{2cm}|}
\hline
\textbf{ID} & \textbf{História de Usuário} & \textbf{Critério de Aceitação} & \textbf{Requisitos} & \textbf{Propriedades} \\
\hline

\textbf{US01} & Como operador, quero visualizar os dados de consumo de bateria e velocidade média para monitorar o desempenho. & O sistema deve atualizar os dados na interface web em tempo real. & RF11, RF13 & Prioridade: Must Have \\ \hline

\textbf{US02} & Como operador, quero consultar os dados de tipo de labirinto, tempo total de execução, trajeto percorrido, status do desafio e posição do micromouse em tempo real para avaliar resultados. & Todos os dados devem ser  visíveis pós-execução. & RF03, RF15, RF17, RF18, RF19 & Prioridade: Must Have \\ \hline

\textbf{US03} & Como operador, quero que os dados das execuções sejam armazenados e permitam consulta posterior para análise histórica. & Os dados devem persistir no banco de dados e ser recuperáveis. & RF20, RF21 & Prioridade: Must Have \\ \hline

\textbf{US04} & Como operador, quero que o micromouse percorra o labirinto de forma autônoma, detectando as paredes durante a navegação e identificando a área central do mesmo.& O micromouse deve chegar a área central sem interferêcia humana, se guiando pelas paredes. & RF01, RF02, RF05 & Prioridade: Must Have 
\\ \hline

\textbf{US05} & Como operador quero que o micromouse consiga resolver labirintos de diferentes dimensões, mapeando a labirinto através da disposição das paredes e decidindo aonde ir com base nos caminhos disponíveis. & O micromouse deve usar as paredes a sua disposição e o caminho que estiver livre para percorrer o labirinto e mapear seu percurso & RF04, RF06, RF07, RF 08 & Prioridade: Must Have 
\\ \hline

\textbf{US06} & Como operador, quero que o micromouse percorra o labirinto mais rapidamente, comparado com a velocidade de mapeamento. & O micromouse deve ser mais veloz no seu percurso, depois de mapear o labirinto. & RF23 & Prioridade: Should Have \\ \hline

\textbf{US07} & Como operador, quero que conseguir visualizar e comparar os dados da trajetória percorrida, consumo de bateria, velocidade média do micromouse, tempo de execução e o mapa do labirinto por meio de uma interface web & O sistema deve exibir o consumo de bateria, velocidade média do micromouse, tempo de execução e o mapa do labirinto em tempo real na interface web. & RF09, RF10, RF12, RF14, RF16, RF22, RF24 & Prioridade: Must Have \\ \hline

\end{tabular}
\end{center}
\label{US}
\end{table}

\subsection{Descrição da Arquitetura da Solução de Software Proposta}

A arquitetura de software foi projetada para orquestrar a navegação autónoma do micromouse e fornecer uma plataforma robusta para monitorização em tempo real e armazenamento do histórico de execuções. O sistema adota o padrão \textbf{Cliente-Servidor} operando em rede local, garantindo independência de serviços externos. A aplicação web foi estruturada sob os princípios do padrão arquitetural \textbf{MVC (Model-View-Controller)}, adaptado para o desenvolvimento web moderno em componentes.

\begin{figure}
    \centering
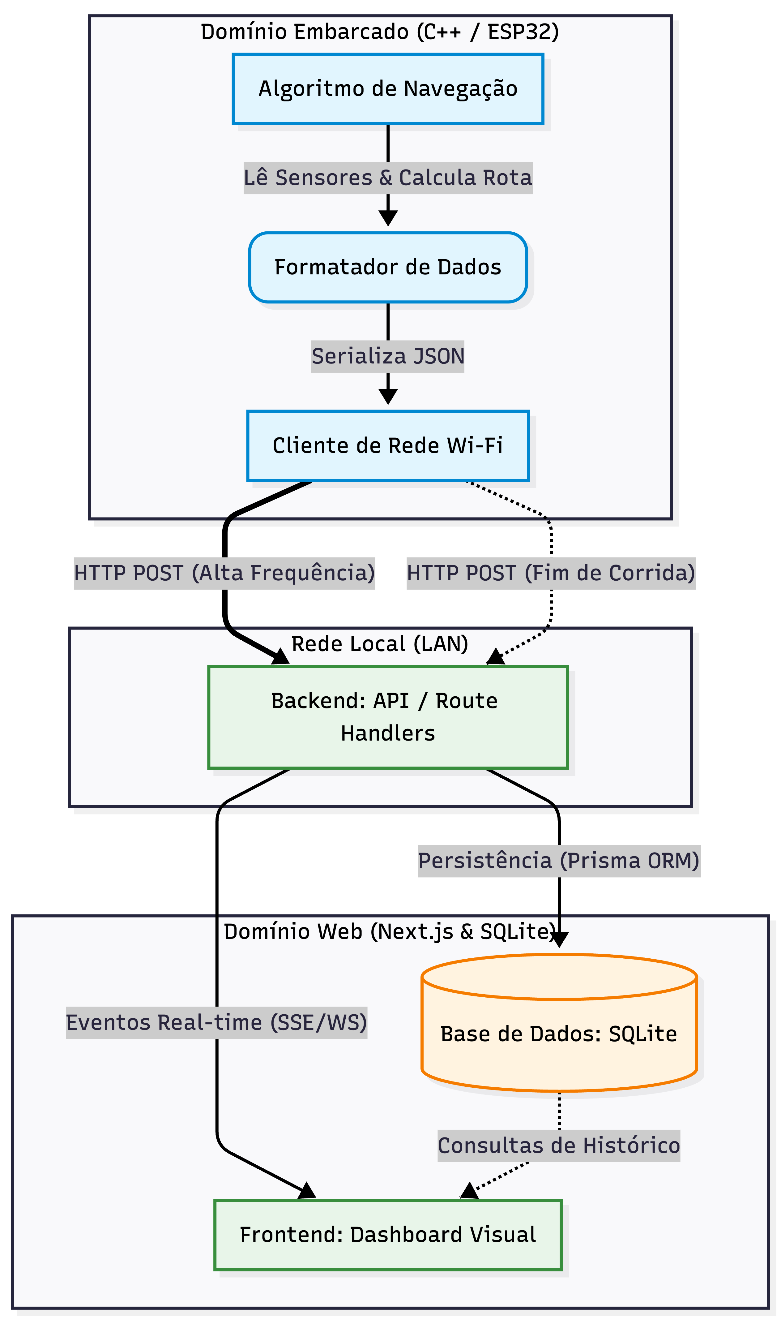
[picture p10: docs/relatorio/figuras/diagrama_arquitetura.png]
    
    \caption{Diagrama da Arquitetura}
    \label{fig:placeholder}
\end{figure}

As tecnologias selecionadas para compor a solução dividem-se em dois escopos principais:
\begin{itemize}
    \item \textbf{Firmware (C++):} Linguagem escolhida pela alta performance na execução dos algoritmos de busca e mapeamento, além de permitir o controlo de baixo nível necessário para comandar atuadores e processar dados de sensores.
    \item \textbf{Sistema Web (TypeScript/JavaScript):} Utilização do framework \textbf{Next.js}, que integra API (Backend) e interface de utilizador (Frontend). Para a persistência, utiliza-se o \textbf{Prisma ORM} com base de dados \textbf{SQLite}, ideal para centralizar os dados localmente.
\end{itemize}

A arquitetura do software é detalhada a seguir, estruturada conforme as visões do modelo $4+1$ do processo unificado:

\subsubsection{Visão Lógica}
O software divide-se nos Blocos de Software Embarcado e Software Web. O \textbf{Bloco de Software Embarcado (C++)} contém a inteligência de navegação: recebe entradas do ambiente, atualiza a matriz do labirinto e toma decisões de rota. Já o \textbf{Bloco de Software Web (Next.js)} lida com todas as informações passadas pelo bloco embarcado, disponibilizando rotas de API e painéis visuais.

\subsubsection{Visão de Processos}
O código C++ opera num laço não-bloqueante para garantir a fluidez da navegação. O algoritmo processa a próxima ação e transmite os dados (mapa, velocidade, tempo e bateria) via rede local. O \textbf{Backend do Next.js} repassa os dados instantaneamente para o navegador via eventos em tempo real, enquanto o \textbf{Frontend} reage às mudanças de estado para atualizar os gráficos dinamicamente.

\subsubsection{Visão de Dados: Modelo Entidade-Relacionamento (MER)}
A camada de dados foi modelada para separar as configurações estáticas dos labirintos das métricas dinâmicas geradas pelo software. 

\begin{description}
    \item[Entidade Labirinto:] Define o ambiente virtual da prova. Atributos: \textit{id} (PK), \textit{tipo} (4x4, 8x8, 16x16), \textit{tamanho\_celula\_cm} e \textit{descricao}.
    \item[Entidade Corrida:] Regista o desempenho de cada tentativa. Atributos: \textit{id} (PK), \textit{labirinto\_id} (FK), \textit{data\_hora}, \textit{tempo\_conclusao}, \textit{velocidade\_media}, \textit{consumo\_bateria}, \textit{desafio\_cumprido} (S/N) e \textit{trajeto\_coordenadas}.
    \item[Relacionamento:] Um \textbf{Labirinto} pode possuir várias \textbf{Corridas}, mas uma \textbf{Corrida} pertence a apenas um \textbf{Labirinto} (Relação 1:N).
\end{description}

O Diagrama Entidade-Relacionamento (DER) correspondente pode ser visualizado na Figura~\ref{fig:der_micromouse}.

\begin{figure}[htbp]
    \centering
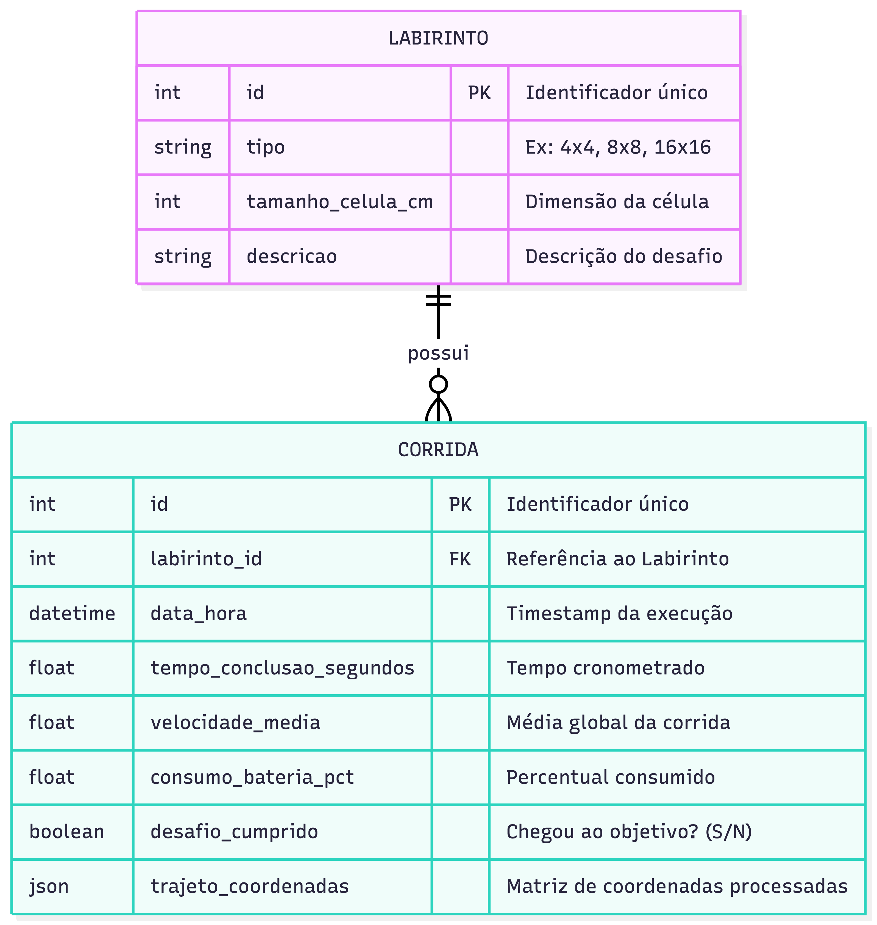
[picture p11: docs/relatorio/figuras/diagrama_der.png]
    
    \caption{Diagrama Entidade-Relacionamento (DER) do Sistema.}
    \label{fig:der_micromouse}
\end{figure}

\subsubsection{Visão de Implementação e Implantação}
O código C++ é modularizado entre a lógica com o Algoritmo Frontier-Based Exploration e funções de I/O. A aplicação web segue a componentização React com comunicação tipada via Prisma. A implantação é feita em \textit{localhost} numa rede isolada para garantir latência mínima e segurança na execução.

\subsubsection{Protótipo de Alta Fidelidade no Figma}

Foi desenvolvido um protótipo de alta fidelidade no Figma para validar a interface e os fluxos de interação do sistema, incluindo a visualização do mapa de ocupação, os painéis de controle do algoritmo Frontier-Based Exploration e a retroalimentação visual em tempo real. O protótipo serviu como base para testes de usabilidade e comunicação entre a equipa de desenvolvimento e os stakeholders. O projeto está disponível no seguinte link: \href{https://www.figma.com/design/hAd6xD3YEXpLAWpT3NWGVL/Projeto-Integrado-1---Mouse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}{Link do Protótipo}. E, além disso, pode ser visualizado na Figura~\ref{fig:prototipo}.

\begin{figure}[htbp]
    \centering

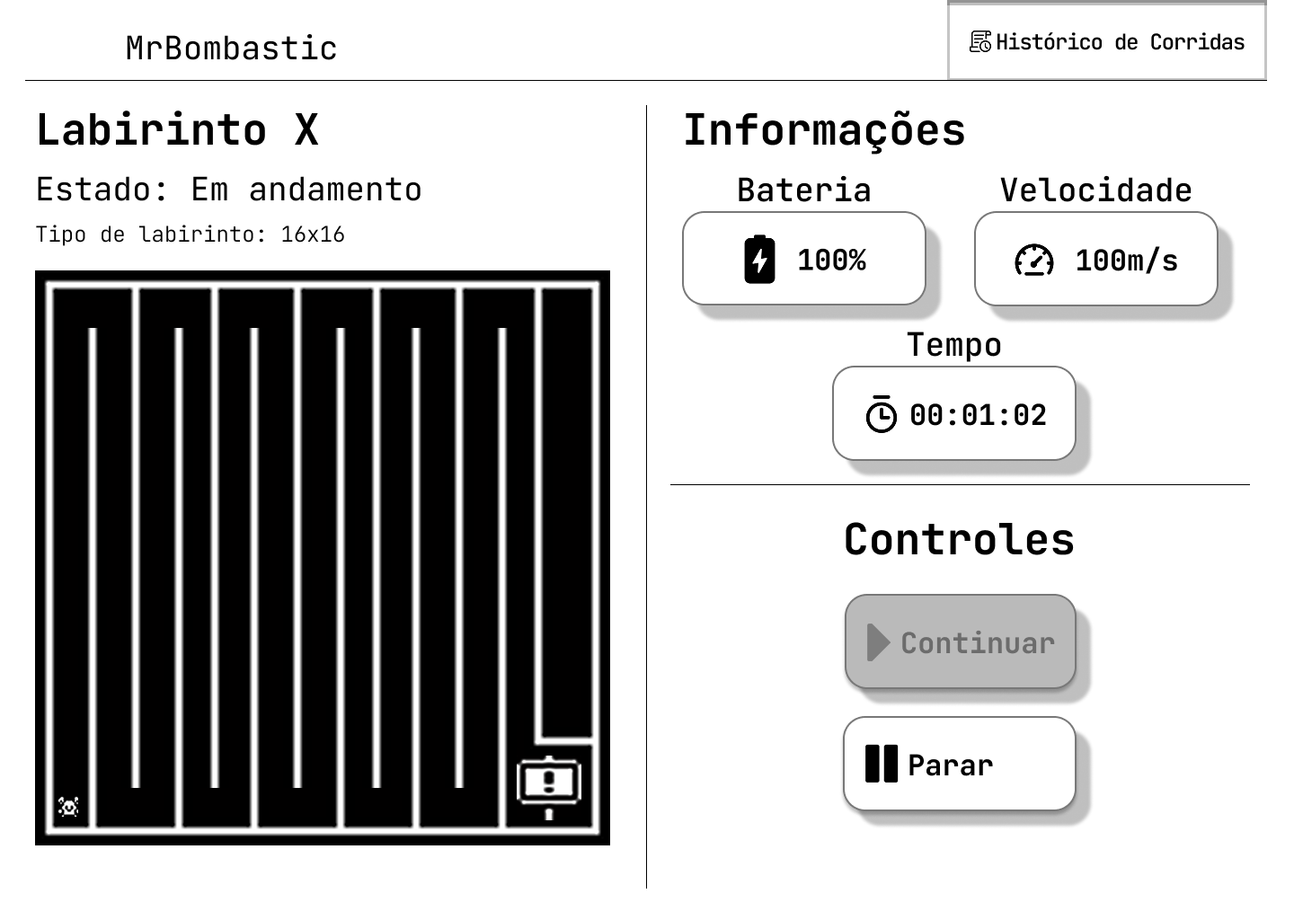
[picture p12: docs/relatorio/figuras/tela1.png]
    \fbox{}
    \hspace{0.5cm}
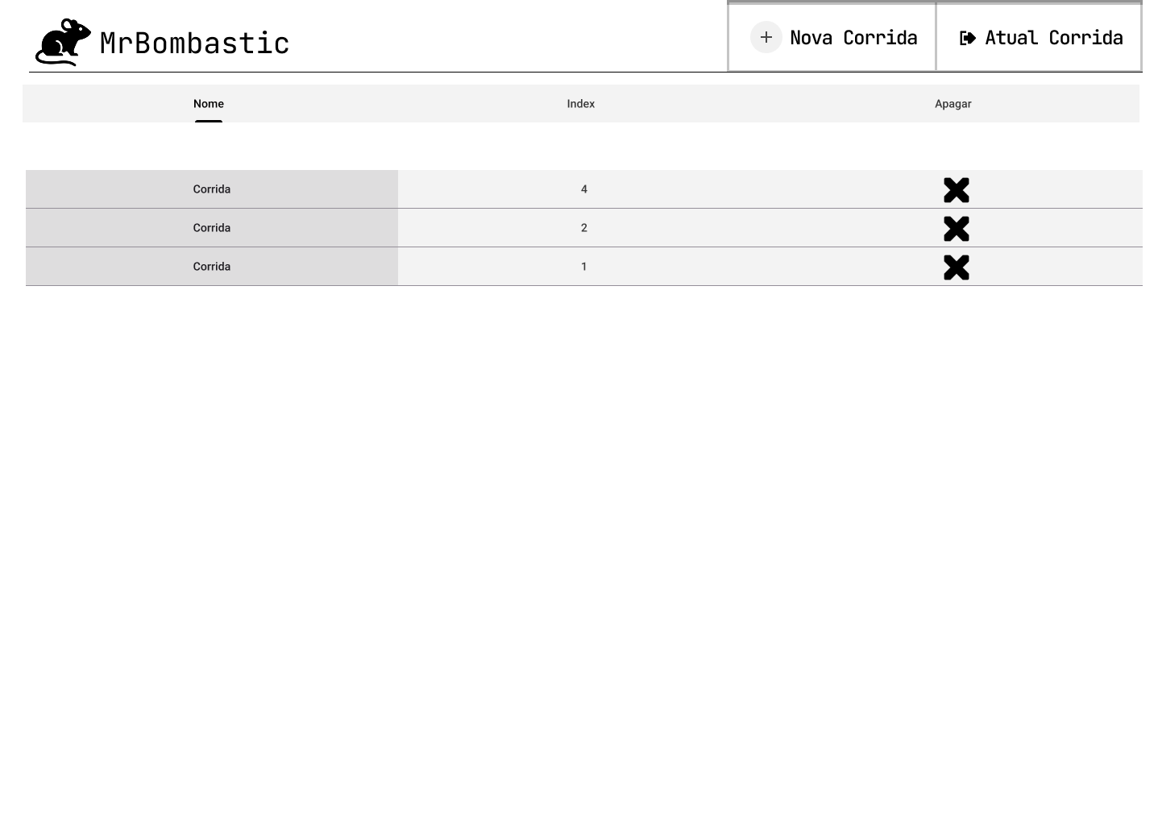
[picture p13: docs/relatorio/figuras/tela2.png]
    \fbox{}
     \\[0.5cm]
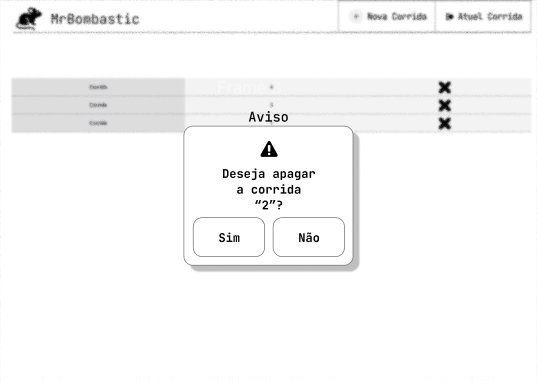
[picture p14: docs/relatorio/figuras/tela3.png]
    \fbox{}

    \caption{Protótipo.}
    \label{fig:prototipo}
\end{figure}

\subsection{Roteiro de Testes Funcionais}

Neste capítulo são apresentados os testes desenvolvidos para verificar o funcionamento correto do Micromouse e garantir que todos os seus módulos operem de forma confiável, precisa e segura. Para isso, foi elaborado um roteiro estruturado de testes funcionais que contempla desde a navegação básica até mecanismos de segurança, mapeamento e comunicação. A Tabela~\ref{tab:roteiro_testes} reúne cada um desses testes, descrevendo seus objetivos, condições necessárias, procedimentos adotados e resultados esperados.

\begin{table}[htbp]
    \centering
    \caption{Roteiro de testes funcionais do sistema}
    \label{tab:roteiro_testes}
    \resizebox{\textwidth}{!}{%
        \begin{tabular}{|l|p{3cm}|p{4cm}|p{3.5cm}|p{4.5cm}|p{4cm}|}
            \hline
            \textbf{Código} & 
            \textbf{Nome} & 
            \textbf{Objetivo} & 
            \textbf{Pré-condições} & 
            \textbf{Procedimentos} & 
            \textbf{Resultado Esperado} \\ 
            \hline
            
            CT-01 & 
            Início da Navegação & 
            Verificar início independente. & 
            Robô na célula inicial e ligado. & 
            1. Acionar ativação.\newline 2. Afastar as mãos e observar. & 
            Início imediato do movimento sem auxílio humano. \\ 
            \hline
            
            CT-02 & 
            Detecção de Paredes & 
            Validar sensores ToF. & 
            Robô em movimento com obstáculo à frente. & 
            1. Deixar o robô navegar.\newline 2. Observar reação frontal. & 
            Detecção da parede e mudança de trajetória antes da colisão. \\ 
            \hline
            
            CT-03 & 
            Telemetria Web & 
            Validar envio de dados Wi-Fi. & 
            Robô conectado; Interface web aberta. & 
            1. Movimentar o robô.\newline 2. Checar painel web. & 
            Exibição de velocidade e bateria com atualização em tempo real. \\ 
            \hline
            
            CT-04 & 
            Parada de Emergência & 
            Garantir parada rápida. & 
            Micromouse em movimento contínuo. & 
            1. Enviar comando de parada.\newline 2. Medir tempo de resposta. & 
            Parada total dos motores em menos de 2 segundos. \\ 
            \hline
            
            CT-05 & 
            Mapeamento & 
            Validar registro do labirinto. & 
            Labirinto estruturado e robô ativo. & 
            1. Executar ciclo de navegação.\newline 2. Conferir mapa gerado. & 
            Geração progressiva do mapa no sistema conforme exploração. \\ 
            \hline
            
            CT-06 & 
            Identificação do Objetivo & 
            Validar alcance da área central. & 
            Robô em busca da área central. & 
            1. Deixar o robô encontrar o centro.\newline 2. Observar status. & 
            Identificação correta do ponto final e sinalização de sucesso. \\ 
            \hline
        \end{tabular}%
    }
\end{table}

%\textcolor{red}{Itens fundamentais:}

%\begin{itemize}
 %   \item \textcolor{red}{ \textbf{Diagrama Atividades UML:}  descrever e explicar o fluxo do comportamento funcional do produto proposto, evidenciando, de forma clara e estruturada, como as atividades são executadas, em que ordem e sob quais condições. Esse diagrama permite compreender o funcionamento dinâmico do sistema, destacando:}

  %  \begin{itemize}
   %     \item \textcolor{red}{ os principais atores (usuários ou sistemas externos) envolvidos no processo;
    %    \item as atividades de negócio realizadas por cada ator ou pelo próprio sistema;
     %   \item os insumos (entradas) necessários para a execução das atividades;
      %  \item os resultados (saídas) gerados ao longo do fluxo;
       % \item os pontos de decisão, paralelismo e sincronização das atividades;
        %\item Entre as notações mais relevantes, destacam-se o estado iniciail e final, atividades, nós de decisão e junção, barras de bifurcação, Raias (\textit{swimlanes}) e Fluxos de controle. }
        %\end{itemize}

%    \item \textcolor{red}{\textbf{\textit{Backlog} do Produto}}
 %   \begin{itemize}
     %   \item \textcolor{red}{ Descrever os   requisitos funcionais (RF) com a técnica de documentação e especificação de história de usuário (HU);}
      %  \item \textcolor{red}{ Descrever os requisitos não-funcionais (RNF) de forma objetiva; Mais facilmente, mais rapidamente, mais responsivo, de fácil uso, são descrições subjetivas não-válidas. Um exemplo de requisito não-funcional de desempenho: ``a página deve carregar em até 5s quando em conexão 4G''. }
      %  \item \textcolor{red}{ Ao descrever os requisitos (RF e RNF), usar a  classificação MoSCoW (\textit{Must have}, \textit{Should have} e \textit{Could have}),  para auxiliar a priorização dos itens do backlog.}
       % \item \textcolor{red}{ Protótipos de interfafe gráfica do \textit{software} em alta fidelidade.}
      %  \begin{itemize}
         %   \item \textcolor{red}{\textbf{ Todas HUs devem conter sua descrição (Eu-Como-Para), critérios de aceitação e protótipos de interface, documentadas no github. }}
         %   \end{itemize} 

    %    \end{itemize}

   % \item \textcolor{red}{ \textbf{Descrição da arquitetura da solução de \textit{software} proposta:}}
   % \begin{itemize}
    
       % \item \textcolor{red}{ Esta subseção deve contemplar o documento de arquitetura do sistema e deve ser estruturado segundo as visões (4+1) previstas no processo unificado (UP): lógica, de processos;  implementação, implantação e dados (substuirá a visão de casos de uso).}
        
        %\item \textcolor{red}{ Propósito do \textit{software} (qual o seu papel no sistema);}
      %  \item \textcolor{red}{ Padrão adotado: MVC, MVP, Microsserviços, Monolítico, etc (Justificar);}
      %  \item \textcolor{red}{ Linguagens de programação: Java, Python, C\#, JavaScript, etc.}
       % \item \textcolor{red}{ \textit{Frameworks} e bibliotecas: Spring Boot, .NET Core, React, Angular, Django, etc.}
       %     \item \textcolor{red}{ Banco de dados: Relacional (PostgreSQL, MySQL, etc) X NãoSQL (MongoDB,etc). }
       % \item \textcolor{red}{Persistência de dados: Modelo Entidade‑Relacionamento (MER) e seu respectivo Diagrama Entidade‑Relacionamento (DER), aplicáveis quando a solução utiliza banco de dados relacional; alternativamente, diagrama de estrutura de documentos, empregado nos casos em que a arquitetura adota banco de dados não relacional.}
       %  \end{itemize}     
    
   % \item \textcolor{red}{\textbf{ Roteiro de testes funcionais:} }
   % \begin{itemize}
       % \item \textcolor{red}{Código do caso de teste;}
      %  \item \textcolor{red}{Nome do caso de teste;}
     %   \item \textcolor{red}{ Objetivo do caso de teste;}
   %     \item \textcolor{red}{ Pré-condições do sistema para o teste ser realizado, quando se aplicar;}
    %    \item \textcolor{red}{ Descrição dos procedimentos a serem executados para o teste;}
     %   \item \textcolor{red}{ Resultado esperado para o teste ser aprovado (pós-condição após realizado o teste);}
  %  \end{itemize}
%\end{itemize}

% \textcolor{red}{Com relação ao \textit{software}, será necessário apresentar os seguintes itens: % pacotes de componentes de \textit{software}, suas funções e características, e explicar as decisões de projeto:
% \begin{enumerate}
%     \item Um diagrama do processo de negócio do problema que a máquina se propõe a resolver (BPNM) – não é UML, mas é fundamental para entender como o sistema se comporta como um todo, incluindo o usuário;
%     \item Lista de casos de uso (backlog do sistema). Backlog funcional;
%     \item Lista de requisitos não-funcionais a serem satisfeitos pelo sistema;
%     \item Diagrama de casos de uso: mostrando os requisitos funcionais, seus atores e como eles interagem entre si;
%     \item Diagrama de Classes: apresentando quais dados são manipulados pelo sistema (internamente e externamente – ex.: resultados de experimentos);
%     \item Diagrama de arquitetura, identificando todos os componentes da máquina e suas iterações com o software;
%     \item Diagrama de estados da máquina (sistema);
%     \item Descrição dos testes dos componentes da máquina e dos testes funcionais que deveriam ser feitos para avaliar o funcionamento da máquina e identificar defeitos. São importantes os testes unitários (componentes) e de integração (conjunto de componentes) e o roteiro de testes.
% \end{enumerate}
% }
%\textcolor{red}{Com relação ao \textit{software}, será necessário apresentar pacotes de componentes de \textit{software}, suas funções e características, e explicar as decisões de projeto.}

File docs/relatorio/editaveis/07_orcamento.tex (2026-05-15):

\begin{landscape}

\chapter{Orçamento}

\begin{table}[htpb]
\begin{center}
\caption{Orçamento geral.}
\begin{tabular}{|c|c|c|}
\hline
\textbf{Geral}          & \textbf{Previsto (R\$)} & \textbf{Realizado (R\$)} \\ \hline
Componentes eletrônicos & 337,76                    & 337,76                     \\ \hline
Estrutura                & 248,23                    & 0,00                     \\ \hline
\end{tabular}
\end{center}
\end{table}

\begin{table}[htpb]
\begin{center}
\caption{Orçamento por aquisição.}
\begin{tabular}{|c|c|c|c|c|}
\hline
\textbf{Item ou serviço} & \textbf{Tipo} & \textbf{Previsto (R\$)} & \textbf{Realizado (R\$)} & \textbf{Responsável} \\ \hline
Kit 2 Mini Regulador de Tensão Step Down 360 & Componentes eletrônicos & 19,99 & 19,99 & Fernando \\ \hline
Mini Motor Redutor DC 6V N20 750 RPM c/ Encoder (2 un.) & Componentes eletrônicos & 133,80 & 133,80 & Fernando \\ \hline
MPU6050 (IMU) & Componentes eletrônicos & 29,95 & 29,95 & Fernando \\ \hline
Sensor VL53L0X (3 un.) & Componentes eletrônicos & 89,70 & 89,70 & Fernando \\ \hline
BMS 2S 20A & Componentes eletrônicos & 19,90 & 19,90 & Fernando \\ \hline
INA219 & Componentes eletrônicos & 21,99 & 21,99 & Fernando \\ \hline
Placa perfurada & Componentes eletrônicos & 22,43 & 22,43 & Fernando \\ \hline
PLA Branco & Estrutura & 83,70 &  & Mariana \\ \hline
PLA Vermelho & Estrutura & 66,76 &  & Mariana \\ \hline
MDF & Estrutura & 66,98 &  & Mariana \\ \hline
Tinta spray preta & Estrutura & 20,99 &  & Mariana \\ \hline
Rodas 68mm para Chassi Robo Robótica (2 un.) & Estrutura & 9,80 &  & Mariana \\ \hline 

\end{tabular}
\end{center}
\end{table}

% \begin{table}[htpb]
% \begin{center}
%\caption{Justificativas para itens ou serviços trocados após a aquisição.}
%\begin{tabular}{|c|c|} \hline
%\textbf{Item ou serviço} & \textbf{Justificativa}  \\ \hline 
%    Martelo &
 %   O material solicitado não foi entregue no prazo pelo fornecedor. \\ \hline
  %  Ferro &
   % Erro no dimensionamento do primeiro material. \\ \hline
%\end{tabular}
%\end{center}
%\end{table}

\end{landscape}

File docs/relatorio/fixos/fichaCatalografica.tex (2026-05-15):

\begin{fichacatalografica}
	\vspace*{\fill}					% Posição vertical
	\hrule							% Linha horizontal
	\begin{center}					% Minipage Centralizado
	\begin{minipage}[c]{12.5cm}		% Largura
	
	\imprimirautor
	
	\hspace{0.5cm} \imprimirtitulo  / \imprimirautor. --
	\imprimirlocal, \imprimirdata-
	
	\hspace{0.5cm} \pageref{LastPage} p. : il. (algumas color.) ; 30 cm.\\
	
	\hspace{0.5cm} \imprimirorientadorRotulo~\imprimirorientador\\
	
	\hspace{0.5cm}
	\parbox[t]{\textwidth}{\imprimirtipotrabalho~--~\imprimirinstituicao,
	\imprimirdata.}\\
	
	\hspace{0.5cm}
		1. \imprimirpalavrachaveum.
		2. \imprimirpalavrachavedois.
        3. \imprimirpalavrachavetres.
        4. \imprimirpalavrachavequatro.
        5. \imprimirpalavrachavecinco.
		I. \imprimirorientador.
		II. Universidade de Brasília.
		III. Faculdade UnB Gama.
		IV. \imprimirtitulo\\ 			
	
	\hspace{8.75cm} CDU \\ %\nomecdu\\
	
	\end{minipage}
	\end{center}
	\hrule
        \pagebreak
\end{fichacatalografica}

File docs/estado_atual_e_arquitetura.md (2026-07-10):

# Estado Atual e Arquitetura — MrBombastic (Micromouse, Grupo 01)

> Documento de levantamento técnico. Faz o **scan das branches**, explica **o que cada parte do projeto faz** (com foco no **Firmware** e na **comunicação entre o hardware e o sistema web**), e identifica os **gaps** de implementação e refatoração.
>
> Escopo analisado: `develop`, `feat/web_socket`, `feat/arquitetura-fsm-imu`, `Firmware`, `SW_97-salvamento-corridas`.

---

## 1. Mapa das branches (o código está fragmentado)

O trabalho de software vive em branches diferentes que **ainda não convergiram**. Este é o fato mais importante do estado atual.

| Branch | Foco | Estado |
|---|---|---|
| **`develop`** | Integração oficial | Web pronto (backend HTTP + frontend). Firmware **antigo** (estrutura #74, comms HTTP não integrada). Sem WebSocket. Frontend com testes Vitest. |
| **`feat/arquitetura-fsm-imu`** | **Resolução do labirinto** (rato) | Firmware **reescrito**: Flood Fill + navegação por PID + encoders + IMU. **Removeu a comunicação com a web.** É o estado de referência para a navegação. |
| **`feat/web_socket`** | Telemetria em tempo real | **Spike** de WebSocket no backend (lib `ws`). Não integrado ao frontend nem ao firmware. |
| **`Firmware`** | Firmware base | Antigo (Issue #74): teste de movimentação hardcoded + drivers básicos. Superado pela `feat/arquitetura-fsm-imu`. |
| **`SW_97-salvamento-corridas`** | Salvamento de corridas | Já **mergeado** na `develop` (PR #98). |

**Resumo:** a resolução do labirinto está numa branch (`feat/arquitetura-fsm-imu`) que **não fala com a web**; a web e a telemetria estão em outras branches (`develop` + `feat/web_socket`) que **não têm a navegação nem o firmware integrado**. Ninguém tem o fluxo completo ponta a ponta.

---

## 2. Hardware e como os componentes se comunicam (Firmware)

Plataforma: **ESP32** (`board = esp32dev`, framework Arduino, PlatformIO). Pinos e endereços em `src/firmware/src/config/pinos.h`.

### 2.1 Componentes e barramentos

```mermaid
graph LR
    subgraph Sensores
      IMU["MPU6050 (IMU)<br/>giroscópio Z"]
      TOF1["VL53L0X Frente"]
      TOF2["VL53L0X Esquerda"]
      TOF3["VL53L0X Direita"]
      ENCE["Encoder Esq."]
      ENCD["Encoder Dir."]
    end
    subgraph Atuação
      DRV["Driver TB6612FNG<br/>(ponte H)"]
      M1["Motor N20 Esq."]
      M2["Motor N20 Dir."]
    end
    ESP["ESP32"]

    IMU -- "I2C (0x68)" --> ESP
    TOF1 -- "I2C (0x30)" --> ESP
    TOF2 -- "I2C (0x31)" --> ESP
    TOF3 -- "I2C (0x32)" --> ESP
    ENCE -- "GPIO/IRQ" --> ESP
    ENCD -- "GPIO/IRQ" --> ESP
    ESP -- "GPIO + PWM" --> DRV
    DRV --> M1
    DRV --> M2
    ESP -. "Wi-Fi (HTTP/WebSocket, JSON)" .-> WEB["Sistema Web (backend)"]
```

### 2.2 Como cada barramento funciona

- **I2C (SDA=21, SCL=22, 400 kHz)** — barramento compartilhado por **4 sensores**:
  - **MPU6050 (IMU)** no endereço fixo `0x68`. Fornece a **velocidade angular no eixo Z** (giro), integrada em **ângulo (heading)** — é a referência de rumo para andar reto e girar 90°/180°.
  - **3× VL53L0X (ToF)** — todos nascem com o **mesmo endereço padrão**, então cada um tem um pino **XSHUT** (26, 4, 23) usado no boot para ligá-los **um de cada vez** e reatribuir endereços únicos (`0x30`, `0x31`, `0x32`). Medem **distância até as paredes** (frente/esquerda/direita) em mm.
- **Encoders de quadratura (GPIO com interrupção)** — esquerdo (32/33) e direito (34/35), lidos pela lib `ESP32Encoder`. Fornecem **odometria** (distância percorrida em cm) para medir "uma célula".
- **Driver de motor TB6612FNG (GPIO + PWM)** — ponte H de 2 canais (AIN1/AIN2/PWMA e BIN1/BIN2/PWMB) + `STBY` (pino 5). O ESP32 controla direção (IN1/IN2) e velocidade (PWM) de cada **motor N20**.
- **Wi-Fi (ESP32 → Web)** — o único canal para o sistema web. Envia **telemetria em JSON**. Hoje esse canal está **desligado** na branch da navegação (ver §5).

### 2.3 Mapa de pinos (referência)

| Função | Pino(s) ESP32 |
|---|---|
| I2C SDA / SCL | 21 / 22 |
| ToF XSHUT (F/E/D) | 26 / 4 / 23 |
| Motor A (IN1/IN2/PWM) | 13 / 25 / 18 |
| Motor B (IN1/IN2/PWM) | 14 / 27 / 19 |
| Driver STBY | 5 |
| Encoder Esq. (A/B) | 32 / 33 |
| Encoder Dir. (A/B) | 34 / 35 |

Libs (PlatformIO): `pololu/VL53L0X`, `adafruit/Adafruit MPU6050` (+ Unified Sensor), `madhephaestus/ESP32Encoder`, `bblanchon/ArduinoJson`.

---

## 3. Camadas de software do Firmware (`feat/arquitetura-fsm-imu`)

Organização em `src/firmware/src/`, no padrão PlatformIO. De baixo para cima:

### 3.1 Sensores (`src/sensores/`)
- `i2c_bus` — inicializa o barramento I2C compartilhado.
- `imu` — MPU6050: `imuInit`, `imuCalibrarOffsetZ`, leitura do giro Z e integração do **ângulo (heading)**.
- `tof` — 3× VL53L0X: `tofInit` (sequência XSHUT), `tofLerDistancia(i)` em mm.
- `encoders` — contagem por interrupção + conversão para **cm percorridos** (`encoderDistanciaEsquerdaCm/DireitaCm`).

### 3.2 Atuadores (`src/atuadores/`)
- `motores` — abstrai o TB6612FNG: init, setar velocidade/direção por canal, `motoresAtualizar()`, parar.

### 3.3 Navegação (`src/navegacao/`) — o "cérebro"
- **`pid`** — controlador PID genérico.
- **`navegacao`** — primitivas de movimento **bloqueantes** controladas por PID:
  - `navAndarUmaCelula()`: anda 1 célula reto, **mantendo o rumo** (PID sobre o ângulo da IMU), com centralização entre paredes via ToF laterais; a distância da célula é medida pelos **encoders**.
  - `navGirarDireita/Esquerda/MeiaVolta()`: giram 90°/180° via PID sobre o **erro de ângulo** da IMU.
  - `navParedeFrente/Esquerda/Direita()`: convertem as leituras ToF em **presença de parede** (booleano).
- **`flood_fill`** — o **algoritmo de resolução do labirinto** (Flood Fill / BFS clássico de micromouse):
  - labirinto `MAZE_N × MAZE_N`, cada célula com 4 bits de parede;
  - `definirParede()` (mantém consistência com a célula vizinha), `calcular()` (BFS a partir do objetivo), `melhorDirecao()` (vizinho acessível de menor distância, com desempate "seguir reto").

### 3.4 Orquestração (`src/main.cpp`) — a máquina de estados
Loop de navegação autônoma, célula a célula:
1. **lê paredes** (ToF) e registra no mapa;
2. **recalcula o Flood Fill** (distâncias até o centro);
3. se **chegou ao objetivo** → para;
4. escolhe a **melhor direção** (menor distância);
5. **orienta** (gira) e **avança uma célula**; atualiza posição/rumo lógicos.

Estado do robô: `robX`, `robY`, `robDir` (NORTE/LESTE/SUL/OESTE), `concluido`. **Depuração só via `Serial`** (`Serial.printf` de posição/distância) — **não há envio para a web**.

### 3.5 Testes de hardware (`src/scripts_teste/` + `tools/`)
Ambientes PlatformIO isolados por componente (`teste_encoders`, `teste_motores`, `teste_imu`, `teste_tof`, `teste_reta_imu`, `teste_giro_imu`) e um script Python (`tools/captura_log.py`) que gerou os CSVs de calibração (`teste_giro_*.csv`, `teste_reta_*.csv`) para ajustar o PID.

---

## 4. Sistema Web — exposição dos dados (`develop`)

### 4.1 Backend (`src/backend`, Express + Prisma/SQLite)
- **Persistência** (`TelemetryService`): agrupa a telemetria por **corrida** (`Run`), cria/anexa automaticamente e **finaliza** a corrida quando chega estado terminal do robô (`OBJETIVO_ENCONTRADO`/`CONCLUIDO` → `CONCLUIDA`; `ERRO` → `NAO_CONCLUIDA`), gravando `endedAt`.
- **API REST** (`/api/telemetria`): `POST /` (recebe telemetria), `GET /latest`, `GET /runs`, `GET /runs/:id`, `GET /runs/:id/telemetries`, `DELETE /runs/:id`.
- **Transporte:** **HTTP puro** (porta 3000). **Sem WebSocket na `develop`.**

### 4.2 Frontend (`src/frontend`, Next.js)
- **Acompanhamento ao vivo** (`run-context`): faz **polling HTTP** — descobre a corrida `EM_ANDAMENTO` via `/runs` e busca a trajetória completa via `/runs/:id/telemetries` (a cada 1s, só atualiza quando há ponto novo).
- **Minimapa** (`minimap.tsx`): desenha o caminho (Set de células visitadas, O(células+telemetrias)) + posição do rato + 🏁 no objetivo.
- **Histórico** (`table-runs`) e **detalhe da corrida** (`/runs/[id]`): listam e reexibem corridas salvas.
- Testes **Vitest** (componentes/contexto) adicionados na `develop`.

### 4.3 Contrato de telemetria (JSON)
```json
{
  "tempo_corrida_ms": 15400, "posicao_x": 3, "posicao_y": 4,
  "direcao_atual": "NORTE", "estado_robo": "EXPLORANDO", "bateria_pct": 82,
  "leitura_sensores": { "dist_frente_cm": 12.5, "dist_esquerda_cm": 4.1, "dist_direita_cm": 15.0 },
  "runId": "corrida-micromouse-v4"
}
```

---

## 5. Comunicação Firmware ↔ Web (o elo que falta)

```mermaid
sequenceDiagram
    participant ROBO as ESP32 (robô)
    participant BE as Backend
    participant DB as SQLite
    participant FE as Frontend
    ROBO->>BE: telemetria JSON (HTTP POST /api/telemetria  OU  WS /ws)
    BE->>DB: TelemetryService.save (agrupa/persiste corrida)
    BE-->>FE: (HTTP) frontend faz polling  /  (WS) broadcast
    FE->>FE: desenha caminho no minimapa
```

Estado por branch:
- **`develop`** — HTTP. Existe `comunicacao/comunicao.cpp` (HTTPClient POST + monta JSON com ArduinoJson), mas **não é chamado pelo `main`** e aponta para o endpoint **errado** (`/telemetry` em vez de `/api/telemetria`). O `runId` é **fixo** (`"corrida-micromouse-v4"`).
- **`feat/web_socket`** — WebSocket (lib `ws`) no backend: `WebSocketServer({ path: "/ws" })` no mesmo servidor HTTP; ao receber mensagem, `TelemetryService.save(...)` e **broadcast para todos os clientes**. Há um `simulate-websocket.ts` (cliente de teste). **Frontend e firmware não usam WS ainda.**
- **`feat/arquitetura-fsm-imu`** — **removeu a comunicação**. O robô navega mas **não envia nada** para a web.

---

## 6. Estado atual consolidado

| Capacidade | Onde está | Funciona? |
|---|---|---|
| Resolução do labirinto (Flood Fill + PID + IMU + encoders) | `feat/arquitetura-fsm-imu` | ✅ no firmware (autônomo, via Serial) |
| Drivers de hardware (IMU/ToF/encoders/motores) | `feat/arquitetura-fsm-imu` | ✅ (com ambientes de teste por componente) |
| Persistência de corridas + API REST | `develop` | ✅ |
| Visualização web (minimapa/histórico ao vivo) | `develop` | ✅ (via polling HTTP) |
| Envio de telemetria pelo robô (#99) | — | ❌ não integrado em nenhuma branch |
| WebSocket ponta a ponta (#103) | `feat/web_socket` (só backend) | 🟡 spike incompleto |
| Integração FE↔BE↔carrinho via Wi-Fi (#101) | — | ❌ |

---

## 7. Gaps — implementações faltando e refatorações

### 7.1 Integração / arquitetura (o maior gap)
- **Consolidar as branches na `develop`**: a navegação (`feat/arquitetura-fsm-imu`) e a web/WS (`develop` + `feat/web_socket`) precisam convergir. Hoje evoluem isoladas e há **conflito estrutural** (o firmware foi reescrito de `src/firmware/*` para `src/firmware/src/*`).
- **Reintroduzir a comunicação no firmware da navegação**: o `main.cpp` do Flood Fill precisa **enviar telemetria** a cada célula (posição, rumo, estado, sensores) — hoje só imprime no Serial. **[#99]**

### 7.2 Firmware
- **Wi-Fi + envio não integrados** (`comunicao` não é chamado pelo `main`; endpoint `/telemetry` errado). **[#99/#101]**
- **`runId` fixo** (`"corrida-micromouse-v4"`) → todas as corridas caem num registro só. Gerar **id único por execução**. **[#97 já suporta no backend]**
- **`MAZE_N` = 4** por padrão no `flood_fill.h` (competição usa 16) — parametrizar/alinhar com o tamanho escolhido no frontend.
- **Bateria e tempo**: `bateria_pct` é enviado como `float`/placeholder e não há leitura real; `tempo_corrida_ms` usa `millis()` (desde o boot, não desde o início da corrida).
- **Estados do robô**: padronizar os valores de `estado_robo` (o backend finaliza a corrida com `OBJETIVO_ENCONTRADO`/`CONCLUIDO`/`ERRO`) — o firmware da navegação ainda não emite esses estados.
- **Logs/status para depuração (#104)**: hoje só via Serial; o critério pede **status do carrinho atualizado durante a navegação** exposto para análise → conectar ao envio de telemetria.

### 7.3 WebSocket (#103) — o spike precisa virar implementação
- **Distinguir robô × navegador**: hoje o broadcast manda a telemetria salva **para todos** (inclusive o robô). Separar papéis (ex.: `/ws/robo` vs `/ws/app`).
- **Reconexão/heartbeat**: **não há** ping/pong nem tratamento de desconexão/reconexão (critério explícito da #103). Falta no backend, no frontend e no firmware.
- **Migrar o frontend** de polling para assinatura WS (elimina o gargalo de polling).
- **Protocolo de mensagem**: padronizar envelope `{ type, payload }` (telemetria, status da corrida, comandos) em vez de enviar o objeto cru.
- **Testes de WS** (conexão, troca de mensagens, estabilidade) — inexistentes.

### 7.4 Web
- **Contrato divergente**: `bateria_pct` documentado como `integer`, mas enviado como `float`; alinhar `contrato_API.md`.
- **Dev server pesado**: `next dev` vigia `src/` inteiro (raiz do Turbopack mal inferida por lockfile duplicado) → travar em máquinas fracas. Fixar `turbopack.root` **ou** remover `src/package-lock.json`.

### 7.5 Testes e documentação (#102)
- Cobertura de **integração ponta a ponta** (robô→backend→frontend) inexistente por falta da integração.
- Documentar a **estratégia de testes** e o **fluxo HTTP anterior** (pré-requisito da migração #103).

---

## 8. Recomendação de sequência (para fechar o ciclo)

1. **Consolidar** `feat/arquitetura-fsm-imu` na `develop` (resolver a mudança de estrutura do firmware).
2. **#99** — reintroduzir o envio de telemetria no `main.cpp` da navegação (JSON do contrato, `runId` único, estados padronizados).
3. **#103** — transformar o spike `feat/web_socket` em implementação: protocolo `{type,payload}`, papéis robô/app, reconexão/heartbeat, migrar o frontend, testes.
4. **#101** — validar FE↔BE↔carrinho via Wi-Fi **sobre o transporte final** (evita integrar duas vezes).
5. **#104/#102** — expor logs/status da navegação via telemetria e documentar/ampliar os testes.

> Observação de dependência: a **#101 não exige a #103** tecnicamente (o HTTP já sustenta a integração), mas fazê-la antes da migração WebSocket gera **retrabalho**. Se a #103 vai acontecer, alinhar a #101 ao WebSocket.

---

*Gerado a partir do scan das branches `develop`, `feat/web_socket`, `feat/arquitetura-fsm-imu`, `Firmware` e `SW_97-salvamento-corridas`.*

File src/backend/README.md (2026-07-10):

# Backend

Diretório da API e servidor do projeto do Micromouse.

## Tecnologias
- Node.js (v20+ recomendado para ambiente WSL/Linux)
- Express
- TypeScript
- Prisma ORM v5 (com SQLite)

## Como Rodar Localmente

1. Acesse a pasta e instale as dependências:
    ```bash
    cd src/backend
    npm install
    ```

2. Sincronize o banco de dados e gere o Prisma Client:
    ```bash
    npx prisma db push
    npx prisma generate
    ```

3. Inicie o servidor de desenvolvimento:
    ```bash
    npm run dev
    # ou diretamente: npx ts-node api/server.ts
    ```

## Estrutura de Pastas (Arquitetura MSC)

- `api/`
  - `routes/`: Definição dos endpoints da API (`/api/telemetry`).
  - `controllers/`: Gerenciamento das requisições e respostas HTTP.
  - `services/`: Regras de negócio e comunicação direta com o banco via Prisma.
  - `server.ts`: Arquivo de inicialização do servidor Express.
- `prisma/`: Esquema do banco de dados (`schema.prisma`) e arquivo local `dev.db`.

> [!TIP]
> Para testar o envio de dados em tempo real sem o robô físico, utilize o script de simulação em `/mocks/teste_stress_api.js`:
> ```bash
> node mocks/teste_stress_api.js              # ~tempo real (300ms entre envios)
> INTERVALO_MS=1 node mocks/teste_stress_api.js   # rajada (teste de estresse)
> ```
> Fluxo de demonstração: na web clique em **Iniciar Gravação**, rode o script acima e veja o caminho ser construído no minimapa; o robô encerra a corrida sozinho ao enviar `OBJETIVO_ENCONTRADO`.

> [!WARNING]
> Código de interface, componentes visuais e regras de negócio do cliente devem ficar exclusivamente na pasta `src/frontend`.

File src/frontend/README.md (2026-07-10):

# Frontend

Diretório da interface de usuário (Dashboard) do projeto.

## Tecnologias
- Next.js (App Router)
- TypeScript
- Tailwind CSS

## Como Rodar Localmente

1. Acesse a pasta e instale as dependências:
    ```bash
    cd src/frontend
    npm install
    ```

2. Inicie o servidor de desenvolvimento:
    ```bash
    npm run dev
    ```

3. Acesse http://localhost:3000 no navegador.

## Estrutura de Pastas

- app/: Páginas, rotas e componentes da interface.
- public/: Arquivos estáticos como imagens e ícones.
- Raiz do diretório: Arquivos de configuração (tailwind.config.ts, tsconfig.json).

> [!WARNING]
> Código de API, rotas de banco de dados e regras de negócio do servidor devem ficar exclusivamente na pasta src/backend.

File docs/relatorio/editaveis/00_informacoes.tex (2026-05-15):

% Dados pessoais
\autor{Arthur Guilherme, Arthur Luiz, Enzo Macedo, Felipe de Castro, Fernando de Melo, João Igor, Magno Luiz, Maria Luisa, Mariana Pereira, Mateus de Alcântara, Raphaela Guimaraes, Renan Pereira, Ricardo Henrique, Tiago Lemes, Vilmar José}

\curso{}

% Dados do trabalho
\titulo{MrBombastic}
\data{2026}
\palavraChaveUm{Projeto Integrador de Engenharia 1}
\palavraChaveDois{Faculdade UnB Gama}
\palavraChaveTres{Micromouse}
\palavraChaveQuatro{Robótica móvel autônoma}
\palavraChaveCinco{Navegação em labirintos}
% Dados da orientacao
\orientador{Prof. Diogo Caetana}
\coorientador{Prof. Bruno, Prof. Hilmer, Prof. Juliana, Prof. Lui}

% % Dados para a ficha catalográfica
% \cdu{02:141:005.6}

% % Dados da aprovação do trabalho
% \dataDaAprovacao{01 de junho de 2013 -- Data da aprovação do trabalho}
% \membroConvidadoUm{Titulação e Nome do Professor Convidado 01}
% \membroConvidadoDois{Titulação e Nome do Professor Convidado 02}

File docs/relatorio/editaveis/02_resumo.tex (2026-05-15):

\begin{resumo}

\textcolor{black}{
Este trabalho apresenta o desenvolvimento de um micromouse autônomo projetado para navegar de forma eficiente em labirintos de diferentes dimensões, buscando alcançar uma área central específica sem qualquer intervenção humana após sua ativação inicial. O sistema deve executar, de maneira independente, tarefas fundamentais como detecção de paredes, monitoramento contínuo da própria posição, mapeamento progressivo do ambiente e identificação do ponto que caracteriza o objetivo do desafio. Para garantir a padronização, foram definidas especificações técnicas que incluem limites físicos do robô, que não deve ultrapassar 25 centímetros em comprimento ou largura, e sua capacidade de adaptação a três configurações distintas de labirinto, variando entre 4x4, 8x8 e 16x16 células, todas estruturadas com dimensões e padrões visuais específicos. Diante dessas condições, o micromouse precisa interpretar corretamente o ambiente, ajustando suas decisões de navegação de acordo com a disposição das paredes e com as possibilidades de rota até o destino final. O projeto também incorpora um sistema de telemetria capaz de exibir em tempo real dados como trajetória percorrida, consumo de bateria, velocidade média e tempo total de execução. Após cada tentativa, essas informações são registradas em banco de dados, permitindo análises posteriores e a comparação de desempenhos em diferentes labirintos, promovendo uma compreensão mais ampla do comportamento do sistema autônomo desenvolvido. Dessa forma, o projeto proporciona uma experiência prática e multidisciplinar que envolve diversas engenharias, estimulando a aplicação integrada desses conceitos e contribuindo para a formação técnica no desenvolvimento de soluções de navegação inteligente em ambientes estruturados.
}

\vspace{\onelineskip}
\noindent
\textbf{Palavras-chave}: \imprimirpalavrachaveum; \imprimirpalavrachavedois; \imprimirpalavrachavetres; \imprimirpalavrachavequatro; \imprimirpalavrachavecinco.

\end{resumo}

% \begin{resumo}
%  O resumo deve ressaltar o objetivo, o método, os resultados e as conclusões 
%  do documento. A ordem e a extensão
%  destes itens dependem do tipo de resumo (informativo ou indicativo) e do
%  tratamento que cada item recebe no documento original. O resumo deve ser
%  precedido da referência do documento, com exceção do resumo inserido no
%  próprio documento. (\ldots) As palavras-chave devem figurar logo abaixo do
%  resumo, antecedidas da expressão Palavras-chave:, separadas entre si por
%  ponto e finalizadas também por ponto. O texto pode conter no mínimo 150 e 
%  no máximo 500 palavras, é aconselhável que sejam utilizadas 200 palavras. 
%  E não se separa o texto do resumo em parágrafos.

%  \vspace{\onelineskip}
    
%  \noindent
%  \textbf{Palavras-chave}: latex. abntex. editoração de texto.
% \end{resumo}

% O resumo é um item obrigatório. Essa parte do relatório será uma visão rápida e clara do projeto desenvolvido. O leitor terá informações como: descrição breve do projeto, principais requisitos, tecnologias necessárias e outras informações relevantes para apresentação. O resumo terá no máximo meia (1/2) página.}

% \textcolor{red}{Ao longo deste texto, as descrições em \textbf{cor vermelha} são meras instruções, não devendo aparecer na versão final do texto. \textbf{Utilize o comentário \% ao invés de apagar estas descrições, para não perder as orientações apresentadas.}}

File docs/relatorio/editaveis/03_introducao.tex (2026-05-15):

\chapter[Introdução]{Introdução}

\textcolor{black}{A disciplina Projeto Integrador de Engenharia 1 (PI1), oferecida pela Universidade de Brasília – Faculdade de Ciências e Tecnologias em Engenharia (UnB–FCTE), proporciona uma experiência prática e interdisciplinar ao reunir estudantes das engenharias Automotiva, Aeroespacial, Eletrônica, Energia e de Software. Fundamentada na metodologia de Aprendizagem Baseada em Projetos (PBL), a disciplina incentiva os alunos a resolverem problemas reais e de elevado valor acadêmico, promovendo a colaboração entre áreas e simulando cenários profissionais de trabalho em equipe.}

\textcolor{black}{O desafio deste semestre consiste no desenvolvimento de um micromouse autônomo capaz de navegar de forma eficiente em labirintos de diferentes dimensões, buscando alcançar uma área central específica sem qualquer intervenção humana após sua ativação. A criação desse tipo de robô tem ganhado destaque no ensino de engenharia e se consolidado como um dos desafios mais tradicionais da área, pois exige o desenvolvimento de sistemas capazes de executar tarefas essenciais, como detecção de paredes, mapeamento progressivo do ambiente, identificação de objetivos e navegação autônoma para encontrar a área central no menor tempo possível \cite{ieee_micromouse_2020}.}

\textcolor{black}{Além do avanço das competições e aplicações acadêmicas, estudos recentes apontam que micromouses têm se consolidado como plataformas eficazes para o desenvolvimento de habilidades em robótica móvel, sensores e algoritmos de navegação. Pesquisas como o Jabuti Project demonstram que a combinação de soluções de baixo custo, sensores infravermelhos e algoritmos clássicos de exploração permite criar sistemas autônomos funcionais e pedagogicamente valiosos. Os resultados obtidos evidenciam que esses robôs são ferramentas robustas para o aprendizado experimental, ampliando a compreensão dos estudantes sobre processos de tomada de decisão, integração de hardware e implementação de estratégias de controle em ambientes estruturados \cite{Projeto_Jabuti}.}

\textcolor{black}{A justificativa deste projeto fundamenta-se na oportunidade de aplicar, de forma integrada, conhecimentos multidisciplinares de engenharia em uma solução prática e de baixo custo. Além de seu valor acadêmico, o projeto reproduz desafios presentes em sistemas autônomos reais, proporcionando aos estudantes experiência na resolução de problemas relacionados à inovação, otimização e navegação inteligente em ambientes estruturados.}

% \textcolor{red}{Esta seção terá no máximo duas páginas para apresentar ao leitor uma breve e atualizada revisão bibliográfica sobre o tema do projeto. A Introdução mostrará ao leitor “como está o mundo atual em relação produto desenvolvido”, ou seja, citará algumas pesquisas com produtos similares, publicadas em Journals ou Teses de Doutorado.}

% \begin{equation}
%     \mathbf{F} = m \mathbf{a}
% \end{equation}

% \begin{equation}
%     x_{1,2} = \frac{-b \pm \sqrt{b^2-4ac}}{2a}
% \end{equation}

% Repare que $b^2-4ac$ pode ser negativo, gerando raízes complexas.

% \textcolor{red}{Além de pesquisas científicas, é essencial que as principais legislações sobre o tema do projeto sejam citadas para atualizar o leitor. Se o grupo ou o professor orientador julgarem relevante, indicadores de mercado devem ser adicionados, como alto custo de produtos similares, baixo número de empresas concorrentes ou número estimado de consumidores finais.}

% \textcolor{red}{A Introdução finalizará com 1 (um) parágrafo de justificativa. Nesse parágrafo, o grupo ressaltará o motivo para determinar que o produto proposto atenda às necessidades atual do mercado/consumidor final ou melhora algum sistema já existente, por exemplo, composto por materiais reciclados.}

% \textcolor{red}{Todas as Tabelas e Figuras devem ser referenciadas ao longo do texto, já que elas são ferramentas para auxiliar no entendimento do mesmo. Use o comando ``\textsf{\textbackslash label\{\}}'' junto a Tabelas e Figuras para referencia-las. A Fig. \ref{fig:exemplo_fig} exemplifica como adicionar imagens ao texto.}

% \textcolor{red}{Para citarem trabalhos, utilizem o comando ``\textsf{\textbackslash cite\{\}}''. Evitem ao máximo o uso de outros comandos, tais como o ``\textsf{\textbackslash citeonline\{\}}''.}

% \begin{figure}[htpb]
% \centering
% \includegraphics[width=\textwidth]{figuras/fga.png}
% \caption{\textcolor{red}{Exemplo de figura adicionada em \LaTeX.}}
% \label{fig:exemplo_fig}
% \end{figure}

% \chapter*[Introdução]{Introdução}
% \addcontentsline{toc}{chapter}{Introdução}

% Este documento apresenta considerações gerais e preliminares relacionadas 
% à redação de relatórios de Projeto de Graduação da Faculdade UnB Gama 
% (FGA). São abordados os diferentes aspectos sobre a estrutura do trabalho, 
% uso de programas de auxilio a edição, tiragem de cópias, encadernação, etc.

% Este template é uma adaptação do ABNTeX2\footnote{\url{https://github.com/abntex/abntex2/}}.

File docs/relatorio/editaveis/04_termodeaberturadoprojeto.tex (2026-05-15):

\chapter{Termo de Abertura do Projeto}

\section{Dados do projeto}
\begin{description}
    \item [Nome do Projeto:] MrBombastic
    \item [Data de abertura:] 09/04/2026
    \item [Código:] 1-A
    \item [Patrocinador:] Universidade de Brasília
    % \item [Responsável:] ???
    \item [Gerente:] Tiago Lemes Teixeira / 231026581 / 231026581@aluno.unb.br / (61) 99584-1973
\end{description}

\section{Objetivos}

\textcolor{black}{
O objetivo do projeto é desenvolver um micromouse autônomo capaz de navegar de forma eficiente em labirintos de diferentes dimensões, alcançando a área central do labirinto sem intervenção humana após sua ativação inicial. O sistema deve realizar detecção de paredes, mapeamento progressivo do ambiente, monitoramento contínuo da posição, tomada de decisões de navegação e registro de telemetria em tempo real. Este objetivo atende aos critérios SMART da seguinte forma:
}

\begin{description}
    \item[\textit{Specific} (específico):] Desenvolver um micromouse autônomo capaz de interpretar o ambiente, identificar paredes, mapear o labirinto e encontrar o caminho até a área central, operando de forma completamente independente. O projeto também inclui a implementação de um sistema de telemetria para registro de trajetória, velocidade, consumo de bateria e métricas de desempenho.
    
    \item[\textit{Measurable} (mensurável):] O desempenho será avaliado pela capacidade do micromouse de completar com sucesso três configurações de labirinto (4x4, 8x8 e 16x16), registrando trajetória percorrida, tempo total, velocidade média e consistência das decisões de navegação.
    
    \item[\textit{Agreed} (acordado):] O objetivo foi definido em conjunto pela equipe do projeto, sob supervisão da Universidade de Brasília, considerando as demandas das áreas de eletrônica, energia, estrutura e software, estando alinhado com as expectativas acadêmicas e formativas das partes envolvidas.
    
    \item[\textit{Realistic} (realista):] O desenvolvimento do micromouse é viável diante dos recursos técnicos disponíveis, do orçamento destinado e das competências multidisciplinares da equipe (sensores, controle, eletrônica e programação), compatíveis com o escopo acadêmico do projeto.
    
    \item[\textit{Time Bound} (limitado no tempo):] O projeto deverá ser concluído até o final do semestre 2026.1, com marcos intermediários estabelecidos no cronograma acadêmico.
\end{description}

\section{Mercado-alvo}

\textcolor{black}{
O mercado-alvo do projeto Micromouse Autônomo engloba diferentes públicos que podem se beneficiar direta ou indiretamente dos resultados e soluções desenvolvidas. Entre eles:
}

\begin{itemize}
    \item \textbf{Estudantes e Pesquisadores de Engenharia:} \\
    O projeto funciona como uma plataforma prática para o estudo de robótica móvel, sensores, algoritmos de navegação, mapeamento e sistemas embarcados, fortalecendo o aprendizado.

    \item \textbf{Competições e Comunidades de Robótica:} \\
    O micromouse é amplamente utilizado em torneios e eventos de tecnologia, onde equipes testam soluções de navegação autônoma. Assim, o projeto contribui para a formação de equipes competitivas e para o avanço de práticas de inovação em ambientes estudantis e científicos.

    \item \textbf{Comunidade Acadêmica e Científica:} \\
    De forma indireta, o projeto promove o avanço da pesquisa em robótica de pequena escala, telemetria, otimização de rotas e sistemas autônomos de baixo custo, incentivando a formação de novos profissionais na área tecnológica.

\end{itemize}

\section{Requisitos}

Os requisitos do MrBombastic definem as funcionalidades e restrições essenciais que o sistema deve cumprir para garantir seu propósito educacional e tecnológico. O sistema neste contexto de requisitos refere-se ao conjunto de algoritmos e lógica computacional. Esses requisitos estão organizados em Requisitos Funcionais (RF) e Requisitos Não Funcionais (RNF), que abrangem, respectivamente, os comportamentos do sistema e as limitações técnicas necessárias para assegurar desempenho, confiabilidade e padronização do projeto.

\begin{table}[htbp]
\begin{center}
\scriptsize
\setlength{\tabcolsep}{4pt}
\renewcommand{\arraystretch}{1}
\caption{Requisitos Funcionais do Sistema (Integrado G2).}
\begin{tabular}{|c|p{13cm}|}
\hline
\textbf{ID} & \textbf{Descrição} \\
\hline
\textbf{RF01} & O sistema deve permitir que o micromouse navegue de forma autônoma em labirintos sem intervenção humana após a ativação inicial. \\ \hline
\textbf{RF02} & O sistema deve ser capaz de detectar paredes durante a navegação. \\ \hline
\textbf{RF03} & O sistema deve monitorar continuamente a posição do micromouse. \\ \hline
\textbf{RF04} & O sistema deve mapear progressivamente o ambiente do labirinto. \\ \hline
\textbf{RF05} & O sistema deve identificar quando o micromouse alcança a área central do labirinto. \\ \hline
\textbf{RF06} & O sistema deve interpretar o ambiente com base na disposição das paredes. \\ \hline
\textbf{RF07} & O sistema deve tomar decisões de navegação com base nas rotas disponíveis. \\ \hline
\textbf{RF08} & O sistema deve adaptar a navegação a diferentes dimensões de labirinto (4x4, 8x8 e 16x16). \\ \hline
\textbf{RF09} & O sistema deve registrar a trajetória percorrida pelo micromouse. \\ \hline
\textbf{RF10} & O sistema deve calcular o consumo de bateria. \\ \hline
\textbf{RF11} & O sistema deve exibir o consumo de bateria. \\ \hline
\textbf{RF12} & O sistema deve calcular a velocidade média do micromouse. \\ \hline
\textbf{RF13} & O sistema deve exibir a velocidade média do micromouse. \\ \hline
\textbf{RF14} & O sistema deve calcular o tempo total de execução. \\ \hline
\textbf{RF15} & O sistema deve exibir o tempo total de execução. \\ \hline
\textbf{RF16} & O sistema deve exibir em tempo real os dados de telemetria por meio de uma interface web. \\ \hline
\textbf{RF17} & O sistema deve exibir o tipo de labirinto. \\ \hline
\textbf{RF18} & O sistema deve exibir o trajeto percorrido. \\ \hline
\textbf{RF19} & O sistema deve indicar o status do desafio (cumprido ou não). \\ \hline
\textbf{RF20} & O sistema deve armazenar os dados das execuções em um banco de dados após a conclusão. \\ \hline
\textbf{RF21} & O sistema deve permitir a consulta dos dados armazenados por labirinto. \\ \hline
\textbf{RF22} & O sistema deve permitir a comparação de desempenho entre diferentes execuções. \\ \hline
\textbf{RF23} & O sistema deve ser capaz de achar o caminho mais rápido após mapeamento do labirinto. \\ \hline
\textbf{RF24} & O sistema deve exibir o labirinto percorrido após a execução. \\ \hline
\end{tabular}
\end{center}
\label{RF}
\end{table}

\begin{table}[htbp]
\begin{center}
\scriptsize
\setlength{\tabcolsep}{4pt}
\renewcommand{\arraystretch}{1}
\caption{Requisitos Não Funcionais do Sistema (Integrado G2).}
\begin{tabular}{|c|p{10cm}|c|}
\hline
\textbf{ID} & \textbf{Descrição} & \textbf{Categoria URPS+} \\
\hline
\textbf{RNF01} & O sistema deve se comunicar com o sistema por wi-fi. & Suportabilidade \\ \hline
\textbf{RNF02} & O micromouse deve parar completamente no tempo de 2s, após receber comando de parada emergência. & Confiabilidade \\ \hline
\textbf{RNF03} & O sistema deve ser capaz de armazenar dados no banco de dados relacional de forma autônoma. & Confiabilidade \\ \hline
\textbf{RNF04} & O micromouse deve ser capaz de fazer uma decisão ao chegar uma célula no tempo de 5s. & Restrição \\ \hline
\textbf{RNF05} & O sistema de interface web deve exibir dados atualizados do micromouse de telemetria sem exceder 500 ms. & Desempenho \\ \hline
\textbf{RNF06} & O sistema de alimentação (bateria) não deve exceder 25\% do peso total do micromouse. & Restrição \\ \hline
\end{tabular}
\end{center}
\label{RNF}
\end{table}

\section{Justificativa}

\textcolor{black}{
Por se tratar de um desafio que integra sensores, atuadores, programação de estratégias de busca e otimização de rotas, o projeto oferece aos estudantes uma oportunidade significativa para preencher lacunas da formação acadêmica, permitindo a aplicação direta de conceitos teóricos em um sistema físico real. Dessa forma, o micromouse serve como plataforma educacional robusta, contribuindo para o desenvolvimento de habilidades essenciais de engenharia e para a compreensão das aplicações práticas dessa tecnologia no contexto profissional.
}

\section{Indicadores}
\textcolor{black}{Alguns dos indicadores que determinam o mercado consumidor e o potencial de aplicação do \textbf{MrBombastic} são:}
\begin{enumerate}
    \item As competições de Micromouse são realizadas há quase 50 anos. O primeiro anúncio de um evento do tipo foi feito pela revista IEEE Spectrum em 1977, que apresentou a proposta do “Amazing Micro-Mouse Maze Contest”, e a primeira competição oficial ocorreu em Nova York em 1979 \cite{christiansen1977}.
    \item O interesse por competições de Micromouse no Brasil vem crescendo, e um exemplo recente é a 3ª edição do RoboChallenge Brasil, realizada pelo Instituto Mauá de Tecnologia em 2024, que contou com mais de 200 robôs competindo em diversas categorias, incluindo Micromouse \cite{maua_robochallenge_2024}.
\end{enumerate}

% \textcolor{red}{Listar até 10 indicadores que determinam o mercado consumidor do produto desenvolvido: exemplo: 1) n° de alunos da FGA que utilizam ônibus às 18:00; 2) n° de usuários do restaurante universitários, 3) número de idosos classificados como público-alvo no DF e no estado de Goiás, 4) n° de empresas de segurança registradas no DF etc.}
% \section{Aprovações}

% \begin{tabular}{ l l }
%   \textbf{Patrocinador:} & \_\_\_\_\_\_\_\_\_\_\_\_\_\_\_\_\_\_\_\_\_\_\_\_\_\_\_\_\_\_\_\_\_\_ \\
%   & \\
%   \textbf{CEO:} & \_\_\_\_\_\_\_\_\_\_\_\_\_\_\_\_\_\_\_\_\_\_\_\_\_\_\_\_\_\_\_\_\_\_ \\
%   & \\
%   \textbf{Gerente:} & \_\_\_\_\_\_\_\_\_\_\_\_\_\_\_\_\_\_\_\_\_\_\_\_\_\_\_\_\_\_\_\_\_\_ \\
% \end{tabular}

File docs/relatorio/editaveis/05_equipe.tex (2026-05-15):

\begin{landscape}

\chapter{Equipe de Trabalho}

\begin{table}[htpb]
\begin{center}
\caption{Composição da equipe.}
\begin{tabular}{|c|c|c|c|c|c|}
\hline
\textbf{Nome} & \textbf{Matrícula} & \textbf{Curso} & \textbf{Telefone} & \textbf{E-mail} & \textbf{Atribuições}\\ \hline
Arthur Guilherme Aquino & 231037656 & Eng. de Software & (61) 99598-8375 & 231037656@aluno.unb.br  & Software \\ \hline
Arthur Luiz Silva Guedes & 231028675 & Eng. de Software & (61) 99515-7955 & 231028675@aluno.unb.br & Eletrônica \\ \hline
Enzo Macedo da Motta de Mello & 231026320 & Eng. Aeroespacial & (61) 99372-6029 & 231026320@aluno.unb.br & Estrutura \\ \hline
Felipe de Castro Quixabeira & 231026812 & Eng. Eletrônica & (61) 98316-9075 &  231026812@aluno.unb.br & Eletrônica \\ \hline
Fernando de Melo Colli & 231026349 & Eng. Eletrônica & (61) 99821-6440  & 231026349@aluno.unb.br & Energia e Eletrônica  \\ \hline
João Igor Pereira da Costa & 231027201 & Eng. de Software & (61) 98333-5353 & 231027201@aluno.unb.br & Eletrônica e Software \\ \hline
Magno Luiz Vale Vieira & 180042696 & Eng. de Software & (61) 98116-9906 & 180042696@aluno.unb.br & Energia e Software \\ \hline
Maria Luisa Alves Rodrigues & 211039617 & Eng. de Software & (61) 99818-1063 & 211039617@aluno.unb.br & Eletrônica \\ \hline
Mariana Pereira Schumann & 231026492 & Eng. Aeroespacial & (61) 98355-9549 & 231026492@aluno.unb.br & Estrutura \\ \hline
Matheus de Alcantara da Silva Campos & 231026509 & Eng. de Software & (61) 99645-6676 & 231026509@aluno.unb.br & Software \\ \hline
Raphaela Guimarães de Araujo dos Santos & 190116072 & Eng. de Software & (61) 98260-6418 & 190116072@aluno.unb.br & Estrutura \\ \hline
Renan Pereira Reis & 222037764 & Eng. de Software & (38) 99181-4003 & 222037764@aluno.unb.br & Software \\ \hline
Ricardo Henrique Silva Rodrigues & 231037727 & Eng. de Software & (61) 99505-3707 & 231037727@aluno.unb.br & Software \\ \hline
Tiago Lemes Teixeira & 231026581 & Eng. de Software & (61) 99584-1973 & 231026581@aluno.unb.br & Gerente Geral \\ \hline
Vilmar Jose Fagundes dos Passos Junior & 231026590 & Eng. de Software & (61) 99647-6197 & 231026590@aluno.unb.br & Estrutura \\ \hline
\end{tabular}
\end{center}
\end{table}

% \begin{table}[htpb]
% \begin{center}
% \caption{Avaliação de desempenho da equipe \textcolor{red}{(a ser preenchida na entrega final do projeto)}.}
% \begin{tabular}{|c|c|c|c|c|c|c|c|}
% \hline
%  & \textbf{Avaliação} & \textbf{Moti-} & \textbf{Comprome-} & \textbf{Conhecimento} & \textbf{Cumpriu} & \textbf{Comuni-} & \textbf{Gestão} \\
%  \textbf{Nome} & \textbf{geral} & \textbf{vação} & \textbf{timento} & \textbf{técnico} & \textbf{prazos} & \textbf{cação} & \textbf{de conflitos} \\ \hline
%
% Arthur Guilherme Aquino & +++ & +++++ & +++++ & +++ & +++ & + & +++ \\ \hline
% Arthur Luiz Silva Guedes & +++ & +++ & +++ & + & +++ & +++++ & +++ \\ \hline
% Enzo Macedo da Motta de Mello & +++++ & +++ & +++++ & +++ & +++ & +++ & +++ \\ \hline
% Felipe de Castro Quixabeira &  &  &  &  &  &  &  \\ \hline
% Fernando de Melo Colli &  &  &  &  &  &  &  \\ \hline
% João Igor Pereira da Costa &  &  &  &  &  &  &  \\ \hline
% Magno Luiz Vale Vieira &  &  &  &  &  &  &  \\ \hline
% Maria Luisa Alves Rodrigues &  &  &  &  &  &  &  \\ \hline
% Mariana Pereira Schumann &  &  &  &  &  &  &  \\ \hline
% Matheus de Alcantara da Silva Campos &  &  &  &  &  &  &  \\ \hline
% Raphaela Guimarães de Araujo dos Santos &  &  &  &  &  &  &  \\ \hline
% Renan Pereira Reis &  &  &  &  &  &  &  \\ \hline
% Ricardo Henrique Silva Rodrigues &  &  &  &  &  &  &  \\ \hline
% Tiago Lemes Teixeira &  &  &  &  &  &  &  \\ \hline
% Vilmar Jose Fagundes dos Passos Junior &  &  &  &  &  &  &  \\ \hline
%
% \multicolumn{8}{c}{\textit{Legenda}: +++++: \textit{atende às expectativas}; +++: \textit{requer pequenas melhorias}; +: \textit{requer grandes melhorias}.} 
% \end{tabular}
% \end{center}
% \end{table}

\end{landscape}

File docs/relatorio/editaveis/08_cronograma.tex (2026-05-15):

\begin{landscape}

\chapter{Cronograma} 

\begin{table}[htpb]
\begin{center}
\caption{Cronograma geral.}
\begin{tabular}{|c|c|c|}
\hline
\textbf{Geral}          & \textbf{Previsto} & \textbf{Realizado} \\ \hline
Início do projeto       & 09/04/2026        & 09/04/2026         \\ \hline
Fim do projeto          & 08/07/2026        & 08/07/2026         \\ \hline
\end{tabular}
\end{center}
\end{table}

\newpage
\thispagestyle{empty}
\begin{table}[htpb]
\centering
\caption{Cronograma por atividade.}
\footnotesize
\resizebox{\textwidth}{!}{
\begin{tabular}{|c|c|c|c|c|c|c|}
\hline
& \textbf{Início} & \textbf{Início} & \textbf{Fim} & \textbf{Fim} & \textbf{Atividades} & \\
\textbf{Atividade} & \textbf{Previsto} & \textbf{Realizado} & \textbf{Previsto} & \textbf{Realizado} & \textbf{Predecessoras} & \textbf{Responsáveis}\\ \hline

1 - Definição da EAP & 09/04/2026 & 09/04/2026 & 03/05/2026 & 03/05/2026 & - & Documentação \\ \hline
2 - Seleção do Microcontrolador e Análise de Conectividade & 12/04/2026 & 12/04/2026 & 04/05/2026 & 04/05/2026 & - & Eletrônica \\ \hline
3 - Dimensionamento & 12/04/2026 & 12/04/2026 & 04/05/2026 & 04/05/2026 & - & Eletrônica \\ \hline
4 - Análise do Consumo Energético & 12/04/2026 & 12/04/2026 & 04/05/2026 & 04/05/2026 & - & Energia \\ \hline
5 - Planejamento do Chassi e do Sistema de Locomoção & 12/04/2026 & 12/04/2026 & 04/05/2026 & 04/05/2026 & - & Estruturas \\ \hline
6 - Planejamento do Labirinto de Testes & 12/04/2026 & 12/04/2026 & 04/05/2026 & 04/05/2026 & - & Estruturas \\ \hline
7 - Backlog do Produto & 27/04/2026 & 27/04/2026 & 04/05/2026 & 04/05/2026 & - & Software \\ \hline
8 - Diagrama Atividades UML & 27/04/2026 & 27/04/2026 & 09/05/2026 & 09/05/2026 & - & Software \\ \hline
9 - Descrição da Arquitetura & 27/04/2026 & 27/04/2026 & 09/05/2026 & 09/05/2026 & 7 & Software \\ \hline
10 - Diagrama de Blocos e Esquemático & 04/05/2026 & 04/05/2026 & 09/05/2026 & 09/05/2026 & - & Eletrônica \\ \hline
11 - Desenho em CAD do Micromouse e do labirinto & 04/05/2026 & 04/05/2026 & 09/05/2026 & 09/05/2026 & 5,6 & Estruturas \\ \hline
12 - Roteiro de testes funcionais do micromouse & 04/05/2026 & 04/05/2026 & 09/05/2026 & 09/05/2026 & 7,8,9 & Software \\ \hline
13 - Definições de Eletrônica & 18/04/2026 & 18/04/2026 & 10/05/2026 & 10/05/2026 & 2,10 & Eletrônica \\ \hline
14 - Definições de Energia & 18/04/2026 & 18/04/2026 & 10/05/2026 & 10/05/2026 & 4 & Energia \\ \hline
15 - Definições de Estruturas & 18/04/2026 & 18/04/2026 & 10/05/2026 & 10/05/2026 & 5,6,11 & Estruturas \\ \hline
16 - Definições de Software & 18/04/2026 & 18/04/2026 & 10/05/2026 & 10/05/2026 & 7,8,9,12 & Software \\ \hline
17 - Ponto de Controle 1 & 20/04/2026 & 20/04/2026 & 11/05/2026 & 11/05/2026 & 13,14,15,16 & Documentação \\ \hline

18 - Montagem do Pack de Bateria 2S & 12/05/2026 &  & 19/05/2026 &  & 14 & Energia \\ \hline
19 - Implementação da camada de comunicação (backend) & 12/05/2026 &  & 21/05/2026 &  & 16 & Software \\ \hline
20 - Implementação da interface (frontend) & 12/05/2026 &  & 21/05/2026 &  & 16 & Software \\ \hline
21 - Montagem e Verificação do Circuito de Alimentação & 19/05/2026 &  & 26/05/2026 &  & 18 & Energia \\ \hline
22 - Fabricação e Impressão do Chassi & 12/05/2026 &  & 01/06/2026 &  & 15 & Estruturas \\ \hline
23 - Integração entre o frontend e o backend & 22/05/2026 &  & 01/06/2026 &  & 3,19 & Software \\ \hline
24 - Testes de Comunicação Wi-Fi e UART & 12/05/2026 &  & 02/06/2026 &  & 30 & Eletrônica \\ \hline
25 - Implementação do algoritmo de navegação & 12/05/2026 &  & 02/06/2026 &  & 16 & Software \\ \hline
26 - Implementação do algoritmo de caminho mínimo & 12/05/2026 &  & 02/06/2026 &  & 16 & Software \\ \hline
27 - Integração dos Componentes na Placa Perfurada & 26/05/2026 &  & 02/06/2026 &  & 21,22 & Eletrônica \\ \hline
28 - Testes dos Motores N20, Encoders e PID & 26/05/2026 &  & 06/06/2026 &  & 22,27 & Eletrônica \\ \hline

29 - Testes Estruturais (Montagem, Encaixes, Carga) & 01/06/2026 &  & 06/06/2026 &  & 22 & Estruturas \\ \hline
30 - Testes ESP32, VL53L0X e MPU-6050 & 02/06/2026 &  & 06/06/2026 &  & 27 & Eletrônica \\ \hline
31 - Testes de Integração do Sistema Completo & 12/05/2026 &  & 07/06/2026 &  & 26,28,29,30 & Todas as equipes \\ \hline
32 - Testes Automatizados em nível funcional (≥70\% cobertura) & 01/06/2026 &  & 07/06/2026 &  & 23 & Software \\ \hline
33 - Testes E2E (Playwright / Cypress) & 01/06/2026 &  & 07/06/2026 &  & 32 & Software \\ \hline
34 - Testes do INA219 e Validação Energética & 04/06/2026 &  & 07/06/2026 &  & 21 & Energia \\ \hline
35 - Ponto de Controle 2 & 12/05/2026 &  & 08/06/2026 &  & 24,29,31,33,34 & Documentação \\ \hline
36 - Testes Finais no labirinto de testes & 09/06/2026 &  & 06/07/2026 &  & - & Todas as equipes \\ \hline
37 - Possíveis alterações & 09/06/2026 &  & 06/07/2026 &  & 36 & Todas as equipes \\ \hline
38 - Relatório Final & 09/06/2026 &  & 08/07/2026 &  & 37 & Documentação \\ \hline

\end{tabular}
}
\end{table}

% \begin{table}[htpb]
%\begin{center}
%\caption{Justificativas para atrasos ou não-conclusão de atividades.}
%\begin{tabular}{|c|c|} \hline
%\textbf{Atividade} & \textbf{Justificativa}  \\ \hline 
    %3 - GHI &
  %  O material solicitado não foi entregue no prazo pelo fornecedor. \\ \hline
   % 5 - MNO &
   % A equipe responsável pelo desenvolvimento não finalizou a atividade. \\ \hline
%\end{tabular}
%\end{center}
%\end{table}

% \begin{table}[htpb]
%\begin{center}
%\caption{Justificativas para atrasos ou não-conclusão de atividades.}
%\begin{tabular}{|c|c|} \hline
%\textbf{Atividade} & \textbf{Justificativa}  \\ \hline 
    %3 - GHI &
  %  O material solicitado não foi entregue no prazo pelo fornecedor. \\ \hline
   % 5 - MNO &
   % A equipe responsável pelo desenvolvimento não finalizou a atividade. \\ \hline
%\end{tabular}
%\end{center}
%\end{table}

%%% Exemplo de tabela que ocupa várias páginas
% \begin{center}
% \begin{longtable}{|l|l|l|}
% \caption{A sample long table.} \label{tab:long} \\

% \hline \multicolumn{1}{|c|}{\textbf{First column}} & \multicolumn{1}{c|}{\textbf{Second column}} & \multicolumn{1}{c|}{\textbf{Third column}} \\ \hline 
% \endfirsthead

% \multicolumn{3}{c}%
% {{\bfseries \tablename\ \thetable{} -- continued from previous page}} \\
% \hline \multicolumn{1}{|c|}{\textbf{First column}} & \multicolumn{1}{c|}{\textbf{Second column}} & \multicolumn{1}{c|}{\textbf{Third column}} \\ \hline 
% \endhead

% \hline \multicolumn{3}{|r|}{{Continued on next page}} \\ \hline
% \endfoot

% \hline \hline
% \endlastfoot

% One & abcdef ghjijklmn & 123.456778 \\
% One & abcdef ghjijklmn & 123.456778 \\
% One & abcdef ghjijklmn & 123.456778 \\
% One & abcdef ghjijklmn & 123.456778 \\
% One & abcdef ghjijklmn & 123.456778 \\
% One & abcdef ghjijklmn & 123.456778 \\
% One & abcdef ghjijklmn & 123.456778 \\
% One & abcdef ghjijklmn & 123.456778 \\
% One & abcdef ghjijklmn & 123.456778 \\
% One & abcdef ghjijklmn & 123.456778 \\
% One & abcdef ghjijklmn & 123.456778 \\
% One & abcdef ghjijklmn & 123.456778 \\
% One & abcdef ghjijklmn & 123.456778 \\
% One & abcdef ghjijklmn & 123.456778 \\
% One & abcdef ghjijklmn & 123.456778 \\
% One & abcdef ghjijklmn & 123.456778 \\
% One & abcdef ghjijklmn & 123.456778 \\
% One & abcdef ghjijklmn & 123.456778 \\
% One & abcdef ghjijklmn & 123.456778 \\
% One & abcdef ghjijklmn & 123.456778 \\
% One & abcdef ghjijklmn & 123.456778 \\
% One & abcdef ghjijklmn & 123.456778 \\
% One & abcdef ghjijklmn & 123.456778 \\
% One & abcdef ghjijklmn & 123.456778 \\
% One & abcdef ghjijklmn & 123.456778 \\
% One & abcdef ghjijklmn & 123.456778 \\
% One & abcdef ghjijklmn & 123.456778 \\
% One & abcdef ghjijklmn & 123.456778 \\
% One & abcdef ghjijklmn & 123.456778 \\
% One & abcdef ghjijklmn & 123.456778 \\
% One & abcdef ghjijklmn & 123.456778 \\
% One & abcdef ghjijklmn & 123.456778 \\
% One & abcdef ghjijklmn & 123.456778 \\
% One & abcdef ghjijklmn & 123.456778 \\
% One & abcdef ghjijklmn & 123.456778 \\
% One & abcdef ghjijklmn & 123.456778 \\
% \end{longtable}
% \end{center}

\end{landscape}

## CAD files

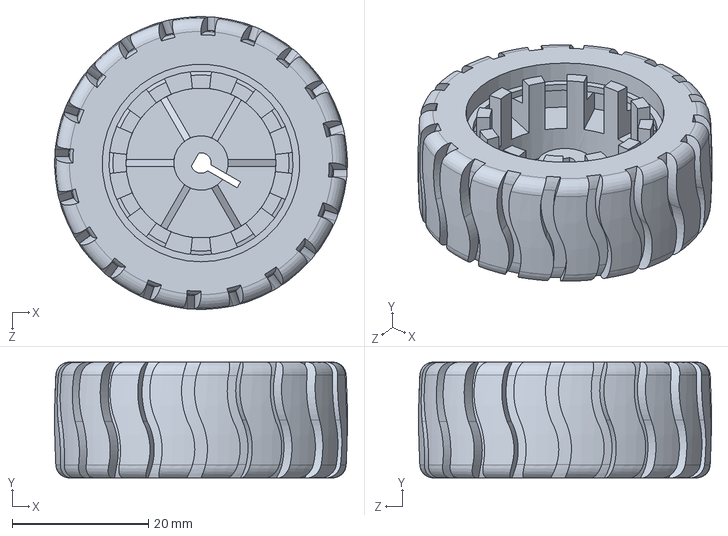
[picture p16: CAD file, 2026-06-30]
mec/Arquivos CAD/CADs Finais/CADs auxiliares da internet/Velg + Ban.SLDPRT
43.0 x 17.0 x 43.0 mm

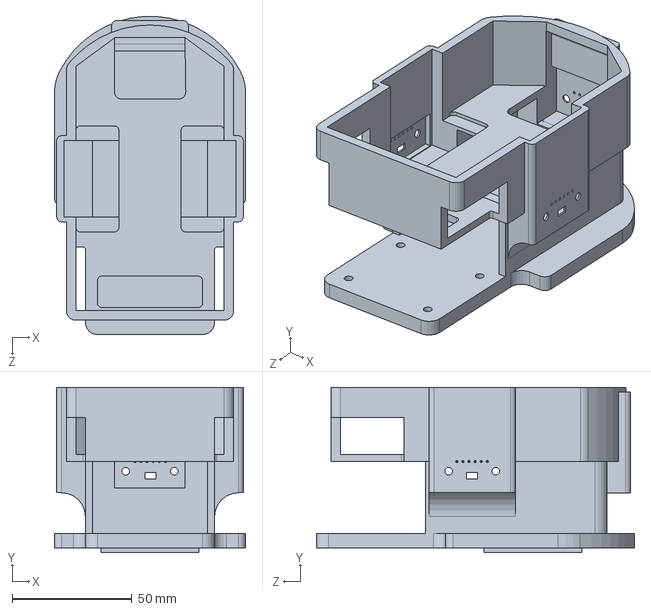
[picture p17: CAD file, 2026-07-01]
mec/Arquivos CAD/CADs Finais/CADs feitos para o projeto/Chassi Final.SLDPRT
80.0 x 69.0 x 132.9 mm

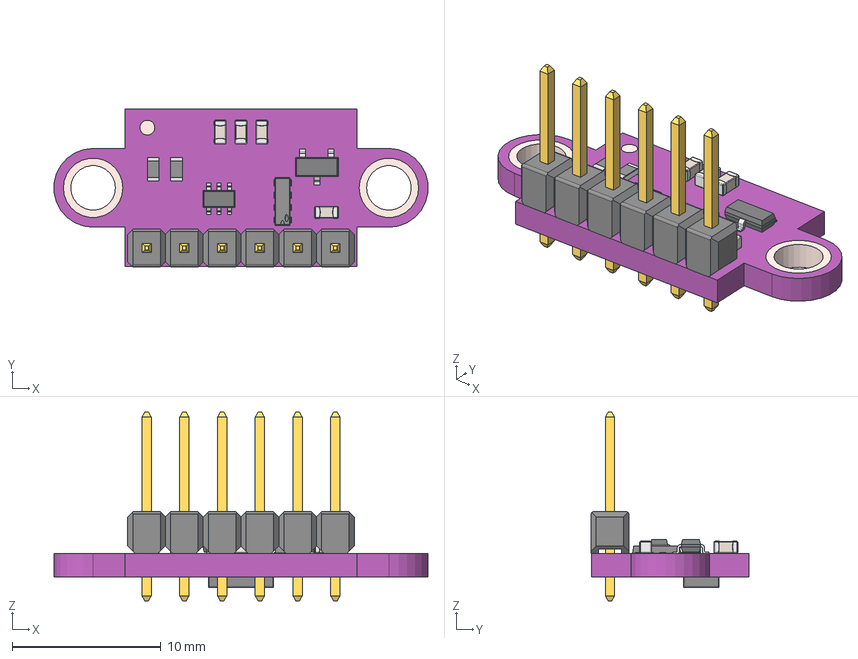
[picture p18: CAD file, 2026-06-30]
mec/Arquivos CAD/CADs Finais/CADs auxiliares da internet/VL53L0X.step
25.2 x 10.6 x 12.7 mm
top
pcb
kork
pads
Document
Document_1
Pin1
Pin2
CeramicBody
Pin1_1
Pin2_1
CeramicBody_1
Pin1_2
Pin2_2
CeramicBody_2
Pin1_3
Pin2_3
CeramicBody_3
SOT-23-3 v1
SOT-23-6 v2
8_Pin_DIP
1x6 TH Pitch 2.54mm v1

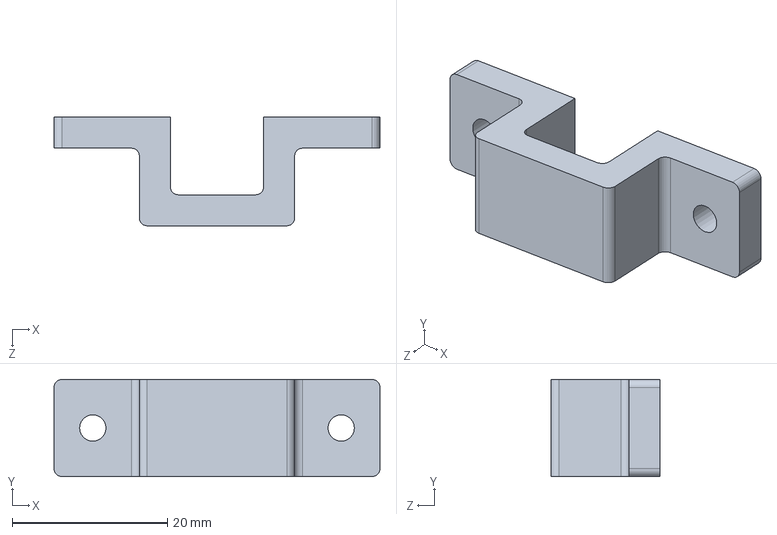
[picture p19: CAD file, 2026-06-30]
mec/Arquivos CAD/CADs Finais/CADs feitos para o projeto/Abraçadeira impressa para os motores.SLDPRT
42.0 x 12.5 x 14.0 mm

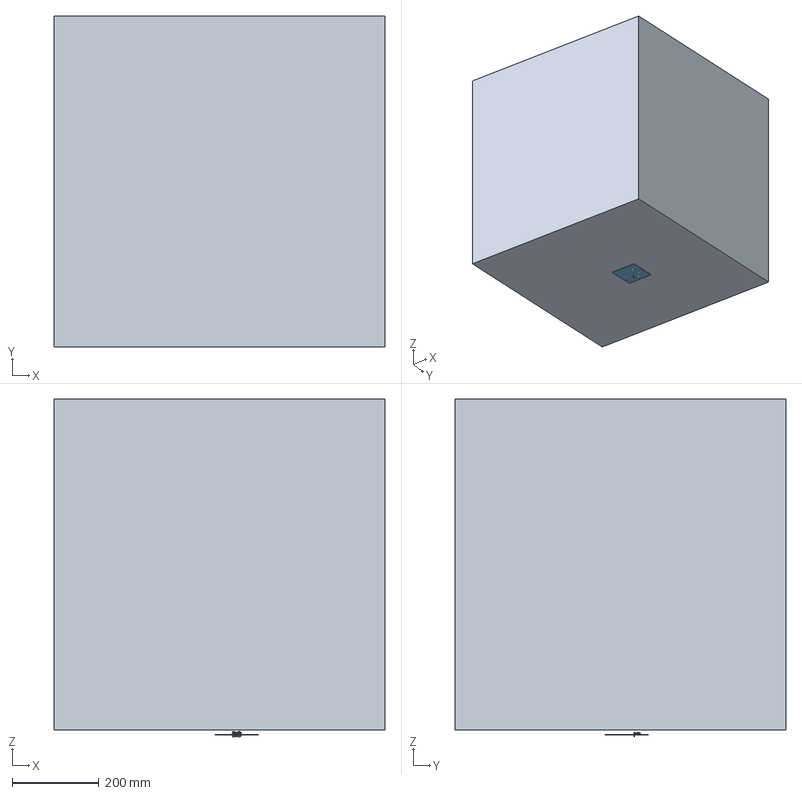
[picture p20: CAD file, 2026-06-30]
mec/Arquivos CAD/CADs Finais/CADs feitos para o projeto/3D_PCB_2026-05-07.step
763.6 x 763.6 x 778.7 mm
Board~nyAc
TopCopper~nyAc
BottomCopper~nyAc
TopFpcStiffener~nyAc
BottomFpcStiffener~nyAc
MPU6050-MODULE~MPU6050~nyAc
INA219~ina219~nyAc

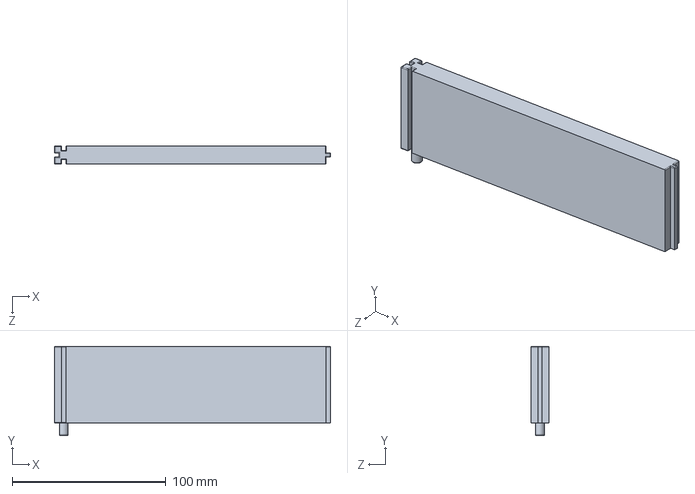
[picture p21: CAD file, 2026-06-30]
mec/Arquivos CAD/CADs Finais/CADs feitos para o projeto/Pinos de fixação com paredes.SLDPRT
179.8 x 58.0 x 12.0 mm

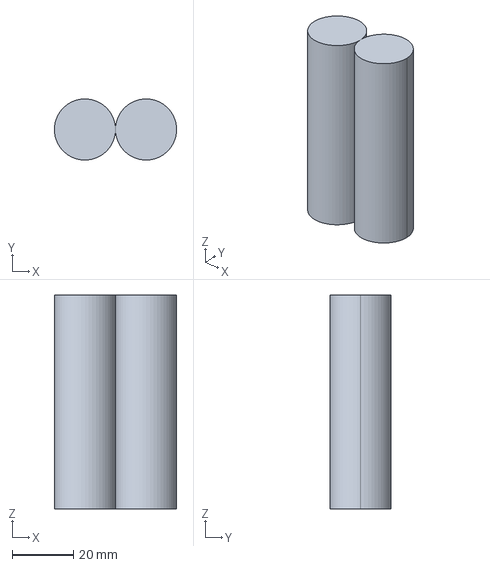
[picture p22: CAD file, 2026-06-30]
mec/Arquivos CAD/CADs Finais/CADs feitos para o projeto/Pack_de_bateria.stp
40.0 x 20.0 x 70.0 mm

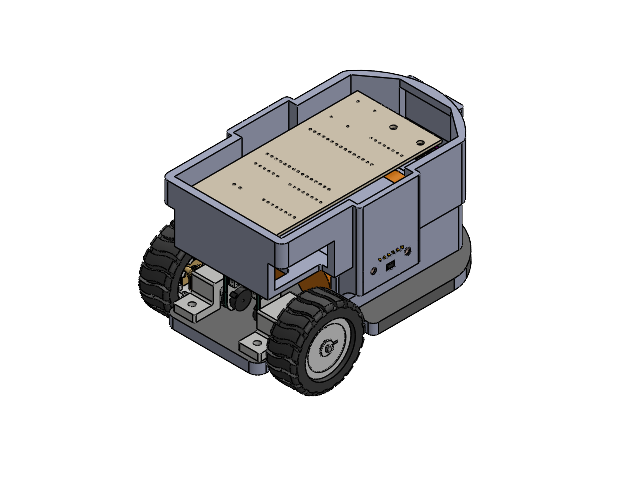
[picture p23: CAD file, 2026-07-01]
mec/Arquivos CAD/CADs Finais/CADs feitos para o projeto/Assembly Final.SLDASM
Chassi Final
Abraçadeira impressa para os motores x 2
Velg + Ban x 2
N20 Mini Micro Metall Gear Motor DC 3-6-12V v1.step x 2
Board~hfon.stp
Pack_de_bateria.stp
top.step x 3
pcb.step x 3
kork.step x 3
pads.step x 3
Pin1.step x 3
Pin2.step x 3
CeramicBody.step x 3
Pin1_1.step x 3
Pin2_1.step x 3
CeramicBody_1.step x 3
Pin1_2.step x 3
Pin2_2.step x 3
CeramicBody_2.step x 3
Pin1_3.step x 3
Pin2_3.step x 3
CeramicBody_3.step x 3
Document.step x 3
Document_1.step x 3
SOT-23-3 v1.step x 3
SOT-23-6 v2.step x 3
8_Pin_DIP.step x 3
VL53L0X_1-0.step x 3
VL53L0X_1-1.step x 3
VL53L0X_1-2.step x 3
VL53L0X_1-3.step x 3
VL53L0X_1-4.step x 3
VL53L0X_1-5.step x 3
VL53L0X_1-6.step x 3
VL53L0X_1-7.step x 3
VL53L0X_1-8.step x 3
VL53L0X_1-9.step x 3
VL53L0X_1-10.step x 3
VL53L0X_1-11.step x 3
VL53L0X_1-12.step x 3
VL53L0X_1-13.step x 3
VL53L0X_1-14.step x 3
VL53L0X_1-15.step x 3
VL53L0X_1-16.step x 3
VL53L0X_1-17.step x 3
VL53L0X_1-18.step x 3
VL53L0X_1-19.step x 3
VL53L0X_1-20.step x 3
VL53L0X_1-21.step x 3
VL53L0X_1-22.step x 3
VL53L0X_1-23.step x 3
VL53L0X_1-24.step x 3
VL53L0X_1-25.step x 3
VL53L0X_1-26.step x 3
VL53L0X_1-27.step x 3
VL53L0X_1-28.step x 3
VL53L0X_1-29.step x 3
VL53L0X_1-30.step x 3
VL53L0X_1-31.step x 3
VL53L0X_1-32.step x 3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

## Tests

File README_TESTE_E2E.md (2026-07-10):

# README (temporário) — Testar tudo junto (E2E)

> Guia rápido para rodar **firmware → backend → frontend** e ver a telemetria ao
> vivo. Documento temporário — some quando o E2E entrar no fluxo oficial.
> Detalhes de arquitetura/decisões em `docs/escopo_websocket_firmware.md`.

## Visão geral

```
  ESP32 (firmware)                      PC (backend + frontend)
  ┌──────────────────┐   Wi-Fi 2,4 GHz  ┌──────────────────────────────┐
  │ Navegação Core 1 │───── ws://──────▶ │ backend  :3000  (WS + REST)  │
  │ Telemetria Core 0│  ?role=robo       │ frontend :3001 (dashboard)   │
  └──────────────────┘                   └──────────────────────────────┘
```

Regra de ouro: **ESP e PC na MESMA rede Wi-Fi 2,4 GHz**, e `WS_HOST` = **IP do PC**.

## Pré-requisitos

- **Node 20+** e **npm**
- **PlatformIO** (`pio`) — CLI ou extensão do VS Code
- Cabo **de dados** USB para a ESP + hotspot/roteador **2,4 GHz**

## 1. Backend (porta 3000)

```bash
cd src/backend
npm install
npx prisma generate
npx prisma migrate dev        # 1ª vez: cria o dev.db
npm run dev                   # "Servidor online: http://localhost:3000"
```

### 1.1 Teste do WebSocket sem firmware

Se você quiser validar só o sistema web/backend, use o simulador de WebSocket:

```bash
cd src/backend
npx tsx api/simulate-websocket.ts
```

Ele conecta como `role=robo`, envia telemetria falsa e fecha a corrida ao final.
Com isso, o frontend só precisa estar aberto em `http://localhost:3001` para observar.

## 2. Frontend (porta 3001)

```bash
cd src/frontend
npm install
npm run dev                   # http://localhost:3001
```

Abra **http://localhost:3001** e clique em **Iniciar** (começa a observar o WebSocket).
No painel da corrida, o tamanho do labirinto escolhido na UI é o valor usado para a corrida atual e para o que fica salvo no banco.

## 3. Descobrir o IP do PC (vai na ESP)

- macOS: `ipconfig getifaddr en0`
- Linux: `hostname -I | awk '{print $1}'`
- Windows: `ipconfig` → "Endereço IPv4" do adaptador Wi-Fi

## 4. Configurar a ESP — `src/firmware/src/config/rede.h`

```c
#define WIFI_SSID "SUA_WIFI"      // MESMA rede do PC, 2,4 GHz
#define WIFI_PASS "SUA_SENHA"
#define WS_HOST   "192.168.x.x"   // IP do PC (passo 3)  — NÃO o IP da ESP
```

## 5. Gravar a ESP

```bash
cd src/firmware
# bancada isolada (telemetria falsa, valida o E2E sem o robô navegar):
pio run -e teste_ws -t upload -t monitor
# depois, navegação real:
pio run -e producao -t upload -t monitor
```

Porta manual, se preciso: `--upload-port <COMx | /dev/cu.* | /dev/ttyUSB0>`.

## 6. O que confirma o E2E

| Onde | Esperado |
| --- | --- |
| Serial da ESP | `Wi-Fi OK IP=192.168.x.x` (mesma faixa do PC) → `conectado ao backend` → pacotes enviados |
| Backend | telemetria chegando |
| Frontend (localhost:3001) | painel + minimapa ao vivo; corrida vira **CONCLUIDA** no fim |

## Teste sem placa (contrato do firmware)

```bash
cd src/firmware && pio test -e native     # 8/8, roda no PC
```

## Testes automatizados

```bash
cd src/backend  && npm test               # Jest
cd src/frontend && npm run test           # Vitest
```

## Teste WebSocket sem firmware

```bash
cd src/backend && npx tsx api/simulate-websocket.ts
```

Esse é o script que valida o fluxo web/backend sem depender do ratinho físico.

## Ver o que foi salvo (opcional)

```bash
cd src/backend && npx prisma studio       # tabelas runs / telemetries
```

---

## Troubleshooting (os erros que mais aparecem)

| Sintoma | Causa | Solução |
| --- | --- | --- |
| `host unreachable` / `desconectado` na ESP | ESP e PC em **redes diferentes**, ou isolamento de clientes do Wi-Fi | mesma Wi-Fi 2,4 GHz; `WS_HOST` = IP do PC; desligar "AP isolation"; testar `ping <IP_da_ESP>` do PC |
| ESP com IP de outra faixa | entrou na Wi-Fi errada | ajustar `WIFI_SSID` para a rede do PC |
| `Cannot GET /` ao abrir `http://IP:3000` | **normal** — o backend respondeu (rota `/` não existe); prova que está acessível | — |
| Frontend não carrega via IP | resolvido: host derivado em runtime (`lib/backend.ts`) | garantir que abriu pelo IP certo |
| ESP não vira porta serial (LED aceso) | cabo só-carga ou placa USB-C sem resistores CC | usar **cabo de dados** e, se USB-C, **cabo USB-A→USB-C** |
| `Wi-Fi FALHOU` | rede 5 GHz | usar 2,4 GHz |

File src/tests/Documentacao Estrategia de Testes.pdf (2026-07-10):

# Documentação de Testes

## Documentação da Estratégia de Testes

### Objetivo

A estratégia de testes adotada teve como principal objetivo garantir a confiabilidade, a estabilidade e a qualidade do sistema por meio da ampliação da cobertura de testes automatizados nas camadas de backend e frontend. Para isso, foram implementados testes unitários e de integração, priorizando os módulos que concentram maior lógica de negócio e impacto funcional na aplicação.

Por decisão da equipe, o firmware foi mantido fora do escopo desta etapa, concentrando os esforços exclusivamente nas aplicações de backend e frontend.

## Estratégia de Testes

### Backend

No backend, foram implementados testes unitários para os métodos das camadas Controller e Service, além de testes de integração para as rotas HTTP da API de telemetria. O objetivo foi validar tanto o comportamento isolado de cada componente quanto a comunicação entre as camadas da aplicação.

Os testes contemplam diferentes cenários de execução, incluindo:

- operações realizadas com sucesso;
- tratamento de exceções e erros internos;
- validação de parâmetros de entrada;
- retornos vazios;
- exclusão de registros;
- recuperação de corridas e telemetrias.

Com a ampliação da suíte de testes, a cobertura do backend evoluiu de aproximadamente 71% para 100%, atendendo plenamente aos critérios estabelecidos para o projeto.

### Frontend

Inicialmente, o frontend possuía apenas testes End-to-End (E2E) desenvolvidos com Playwright. Durante esta atividade, foi configurada uma infraestrutura dedicada à execução de testes unitários utilizando Vitest em conjunto com a React Testing Library.

Foram desenvolvidos testes para funções utilitárias, componentes React, gerenciamento de estado por meio da Context API, controle das corridas e exibição das informações de telemetria.

Os arquivos MockFakeData.ts e FakeTips.ts foram desconsiderados do cálculo da

cobertura, uma vez que contêm apenas dados estáticos e definições de tipos, sem lógica de execução que justifique a implementação de testes automatizados.

Ao término da implementação, a cobertura global do frontend atingiu 99,62%, superando com ampla margem o limite mínimo de 70% definido para o projeto.

## Ferramentas Utilizadas

Para a implementação e execução dos testes foram utilizadas as seguintes ferramentas:

### Backend

- Jest – framework para execução de testes unitários;
- Supertest – realização de testes de integração nas rotas HTTP;
- Prisma Mock – simulação da camada de persistência de dados;
- npm – gerenciamento de dependências e execução dos scripts de teste.

### Frontend

- Vitest – framework para testes unitários;
- React Testing Library – testes de componentes React sob a perspectiva do usuário;
- jsdom – simulação do ambiente do navegador durante a execução dos testes;
- Playwright – manutenção dos testes End-to-End já existentes;
- npm – gerenciamento das dependências e execução dos testes.

## Fluxo de Execução dos Testes

### Backend

A execução da suíte de testes do backend segue o seguinte fluxo:

1. acessar o diretório src/backend;
2. instalar as dependências do projeto utilizando npm install;
3. executar os testes com npm test;
4. gerar o relatório de cobertura utilizando npm run test:coverage;
5. analisar os resultados e verificar se todos os testes foram aprovados e se os índices mínimos de cobertura foram atingidos.

### Frontend

Para o frontend, o fluxo de execução é semelhante:

1. acessar o diretório src/frontend;
2. instalar as dependências com npm install;
3. executar os testes unitários utilizando npm test;
4. gerar o relatório de cobertura com npm run test:coverage;
5. validar os resultados obtidos e analisar os percentuais de cobertura apresentados.

## Novos Testes Implementados

### Backend

Foram adicionados testes unitários e de integração para ampliar a cobertura da API de telemetria.

Controller
- getRuns();
- getRunById();
- getTelemetriesByRunId().

Service
- getRuns();
- getRunById();
- getTelemetriesByRunId().

Integração
- GET /runs;
- GET /runs/:id;

- GET /runs/:id/telemetries.

### Frontend

Foram implementados testes unitários para os seguintes módulos:
- utils.ts;
- run-context.tsx;
- control-panel.tsx;
- control-sizeMaze.tsx;
- navbar.tsx;
- minimap.tsx;
- telemetria-panel.tsx;
- table-runs.tsx.

Esses testes validam funções utilitárias, componentes visuais, gerenciamento de estado, eventos de interação do usuário e regras de negócio presentes na interface da aplicação.

## Resultados Obtidos

Após a implementação dos novos testes, foram obtidos os seguintes resultados:

### Backend

- 70 testes executados;
- 70 testes aprovados;
- 100% de cobertura em Statements, Branches, Functions e Lines.

### Frontend

- 71 testes executados;
- 71 testes aprovados;
- 99,62% de cobertura global do código.

Os resultados demonstram que a suíte de testes atende aos critérios de qualidade estabelecidos para o projeto, proporcionando elevada confiabilidade tanto para as funcionalidades do backend quanto do frontend.

## Armazenamento da Documentação

Toda a documentação produzida durante esta atividade foi armazenada juntamente ao projeto e versionada no repositório, permitindo sua manutenção em conjunto com o código-fonte.

Da mesma forma, os testes implementados foram integrados à branch develop, garantindo que possam ser executados continuamente durante o processo de desenvolvimento e evolução do sistema.

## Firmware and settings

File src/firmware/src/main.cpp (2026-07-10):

#include <Arduino.h>
#include <WiFi.h>
#include "config/pinos.h"
#include "sensores/i2c_bus.h"
#include "sensores/energia.h"
#include "sensores/tof.h"
#include "sensores/imu.h"
#include "atuadores/motores.h"
#include "navegacao/navegacao.h"
#include "navegacao/flood_fill.h"
#include "comunicacao/telemetria.h"

// =============================================================================
// MICROMOUSE — Navegação por FLOOD FILL com movimento controlado por PID.
//
// Sistema de coordenadas:
//   - Origem (0,0) no canto inferior-esquerdo.
//   - Robô começa em (0,0) olhando para o NORTE.
//   - x cresce para LESTE, y cresce para o NORTE.
//
// Fluxo por célula:
//   1. lê paredes (frente/esq/dir) e registra no mapa;
//   2. recalcula o flood fill;
//   3. se chegou ao objetivo, para;
//   4. escolhe o vizinho de menor distância e vai até ele.
// =============================================================================

FloodFill labirinto;

// Estado do robô no mapa.
uint8_t  robX = 0;
uint8_t  robY = 0;
Direcao  robDir = NORTE;

bool concluido = false;
bool iniciado  = false;   // trava de largada: só anda depois do comando 'g'
uint32_t inicioCorridaMs = 0;

// --- Telemetria WiFi (mesma rede da bancada teste_navegacao) ---
const char*    WIFI_SSID  = "Mr Alcatra";
const char*    WIFI_PASS  = "01020405";
const uint16_t WIFI_PORTA = 8080;
WiFiServer server(WIFI_PORTA);
WiFiClient client;

void conectarWiFi();
void logLinha(const String& s);
bool lerComando(char& c);

// Converte direção relativa (frente/esq/dir) do robô em direção absoluta.
static inline Direcao dirFrente(Direcao h)  { return h; }
static inline Direcao dirDireita(Direcao h) { return (Direcao)((h + 1) & 3); }
static inline Direcao dirEsquerda(Direcao h){ return (Direcao)((h + 3) & 3); }

// Move a posição lógica uma célula na direção dada.
static void avancarPosicao(Direcao d) {
    switch (d) {
        case NORTE: robY++; break;
        case LESTE: robX++; break;
        case SUL:   robY--; break;
        case OESTE: robX--; break;
    }
}

// Lê os sensores e grava as paredes vistas na célula atual.
static void registrarParedes() {
    if (navParedeFrente())   labirinto.definirParede(robX, robY, dirFrente(robDir),  true);
    if (navParedeDireita())  labirinto.definirParede(robX, robY, dirDireita(robDir), true);
    if (navParedeEsquerda()) labirinto.definirParede(robX, robY, dirEsquerda(robDir),true);
}

// Gira o robô (física + estado lógico) para a direção absoluta desejada.
static void orientarPara(Direcao destino) {
    uint8_t diff = (destino - robDir) & 3;
    if (diff != 0) {
        // Plano A: se há parede À FRENTE (junção L/T), esquadra ANTES de girar —
        // encosta na parede -> esquadra o rumo + minimiza o offset do eixo -> a
        // roda traseira não raspa. Em cruzamento aberto, gira direto (giro limpo).
        if (navParedeFrente()) {
            if (!navEsquadrar()) logLinha("[MAIN] AVISO: esquadro nao tocou a parede da frente.");
        }
        switch (diff) {
            case 1: navGirarDireita();   break;
            case 2: navGirarMeiaVolta(); break;   // 180: Inc.4 troca por sair de ré
            case 3: navGirarEsquerda();  break;
        }
    }
    robDir = destino;
}

void setup() {
    Serial.begin(115200);
    Serial.println("\n=== MICROMOUSE FLOOD FILL ===");

    i2cInit();

    if (!energiaInit()) {
        Serial.println("[MAIN] AVISO: INA219 nao inicializou; usando leitura de reserva.");
    }

    if (!imuInit())     { Serial.println("[MAIN] ERRO: IMU.");    while (true); }
    imuCalibrarOffsetZ(800);   // 500 = offset do giro menos ruidoso (casa com a bancada)
    imuZerarAnguloZ();

    if (!tofInit())     { Serial.println("[MAIN] ERRO: ToF.");    while (true); }
    if (!motoresInit()) { Serial.println("[MAIN] ERRO: Motores.");while (true); }
    if (!navInit())     { Serial.println("[MAIN] ERRO: Nav.");    while (true); }

    labirinto.iniciar();              // paredes zeradas + moldura + objetivo central
    navZerarRumo();

    // Sobe a telemetria (Wi-Fi + WebSocket) numa task no Core 0. A navegação
    // segue no loop() (Core 1) sem ser travada pela rede.
    telemetriaInit();

    conectarWiFi();
    logLinha("=== PRONTO: robo em (0,0) olhando NORTE. Envie 'g' para INICIAR. ===");
}

void loop() {
    // Aceita/atualiza o cliente de telemetria (nc <IP> 8080).
    if (server.hasClient()) {
        if (!client || !client.connected()) {
            if (client) client.stop();
            client = server.available();
            logLinha("=== Conectado. 'g' inicia a corrida | 'p' para. ===");
        } else {
            server.available().stop();   // já tem cliente: recusa o segundo
        }
    }

    // Comandos: 'g' inicia a corrida; 'p' para (só surte efeito ENTRE movimentos —
    // as primitivas são bloqueantes, então o 'p' fica no buffer e é lido ao fim da
    // célula atual; latência de ~1 célula. E-stop imediato fica p/ a opção 2).
    char c;
    while (lerComando(c)) {
        if ((c == 'g' || c == 'G') && !iniciado) {
            iniciado = true;
            inicioCorridaMs = millis();
            logLinha("=== INICIANDO CORRIDA ===");
            telemetriaAtualizar(millis() - inicioCorridaMs, robX, robY, robDir,
                                "EXPLORANDO");
        } else if ((c == 'p' || c == 'P') && iniciado && !concluido) {
            logLinha("=== PARADO pelo 'p'. Reset p/ rodar de novo. ===");
            navParar();
            concluido = true;
        }
    }

    // Trava de largada: o robô fica PARADO até você mandar 'g'.
    if (!iniciado) {
        delay(20);
        return;
    }

    if (concluido) {
        navParar();
        motoresAtualizar();
        delay(50);
        return;
    }

    // 1. Mapeia o que o robô enxerga na célula atual.
    registrarParedes();

    // 2. Recalcula distâncias até o objetivo.
    labirinto.calcular();
    telemetriaAtualizar(millis() - inicioCorridaMs, robX, robY, robDir,
                        "EXPLORANDO");

    {
        char buf[96];
        snprintf(buf, sizeof(buf), "[POS] (%u,%u) rumo=%u  dist=%u",
                 robX, robY, robDir, labirinto.distancia(robX, robY));
        logLinha(buf);
    }

    // 3. Chegou ao centro?
    if (labirinto.ehObjetivo(robX, robY)) {
        logLinha("=== OBJETIVO ALCANCADO! ===");
        labirinto.imprimirSerial();   // mapa de distâncias (só Serial)
        navParar();
        concluido = true;
        // Estado terminal → backend finaliza a corrida como CONCLUIDA.
        telemetriaAtualizar(millis() - inicioCorridaMs, robX, robY, robDir,
                            "OBJETIVO_ENCONTRADO");
        return;
    }

    // 4. Decide o próximo passo pelo flood fill.
    Direcao proxima;
    if (!labirinto.melhorDirecao(robX, robY, robDir, proxima)) {
        logLinha("[MAIN] Preso: nenhuma direcao valida.");
        navParar();
        concluido = true;
        // Estado terminal → backend finaliza a corrida como NAO_CONCLUIDA.
        telemetriaAtualizar(millis() - inicioCorridaMs, robX, robY, robDir,
                            "ERRO");
        return;
    }

    // 5. Move para a próxima célula.
    uint8_t diff = (proxima - robDir) & 3;
    float cm = 0.0f;
    bool ok;
    if (diff == 2) {
        // Beco / meia-volta: SAI DE RÉ (não gira 180 no lugar — a frente comprida
        // varreria a parede lateral). Mantém o rumo; só a posição recua uma célula.
        ok = navAndarUmaCelula(true, &cm);
    } else {
        orientarPara(proxima);            // esquadro (se parede à frente) + giro c/ viés
        ok = navAndarUmaCelula(false, &cm); // saída: completa o resíduo + centraliza
    }
    {
        char buf[96];
        snprintf(buf, sizeof(buf), "[MOV] %s andou %.1f cm | rumo %.1f deg%s",
                 (diff == 2) ? "re" : "frente", cm, imuLerAnguloZ(), ok ? "" : "  <<< CURTO");
        logLinha(buf);
    }

    // Sem feedback de sucesso, um movimento incompleto (stall/jam) dessincronizaria o
    // mapa em silêncio. Melhor PARAR com diagnóstico do que decidir errado em cascata.
    if (!ok) {
        logLinha("[MAIN] Movimento incompleto -> parando p/ nao dessincronizar o mapa.");
        navParar();
        concluido = true;
        return;                           // NÃO avança a posição lógica
    }
    avancarPosicao(proxima);
    telemetriaAtualizar(millis() - inicioCorridaMs, robX, robY, robDir,
                        "EXPLORANDO");
}

// -----------------------------------------------------------------------------
// Telemetria WiFi
// -----------------------------------------------------------------------------
void conectarWiFi() {
    Serial.printf("[MAIN] Conectando em \"%s\" (DHCP) ...\n", WIFI_SSID);
    WiFi.mode(WIFI_STA);
    WiFi.setSleep(false);
    WiFi.begin(WIFI_SSID, WIFI_PASS);
    uint32_t t0 = millis();
    while (WiFi.status() != WL_CONNECTED && millis() - t0 < 8000) {
        delay(300);
        Serial.print(".");
    }
    if (WiFi.status() == WL_CONNECTED) {
        Serial.printf("\n[MAIN] Wi-Fi OK. Conecte em  %s:%u\n",
                      WiFi.localIP().toString().c_str(), WIFI_PORTA);
        server.begin();
    } else {
        Serial.println("\n[MAIN] Wi-Fi FALHOU. Da p/ iniciar pelo Serial ('g') mesmo assim.");
    }
}

// Manda a linha pra Serial E pro cliente WiFi (se houver).
void logLinha(const String& s) {
    Serial.println(s);
    if (client && client.connected()) client.println(s);
}

// Lê 1 caractere do Serial ou do cliente WiFi. true se leu algo.
bool lerComando(char& c) {
    if (Serial.available() > 0) { c = (char)Serial.read(); return true; }
    if (client && client.connected() && client.available() > 0) {
        c = (char)client.read();
        return true;
    }
    return false;
}

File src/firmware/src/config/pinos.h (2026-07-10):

#pragma once

// --- Barramento I2C ---
#define I2C_SDA_PIN   21
#define I2C_SCL_PIN   22
#define I2C_FREQ_HZ   400000  

// --- IMU MPU6050 ---
#define MPU6050_ADDR  0x68  

// --- Sensores ToF VL53L0X ---
#define NUM_TOF       3

constexpr int     TOF_XSHUT_PINS[NUM_TOF] = { 26, 4, 23 };
constexpr uint8_t TOF_ADDRESSES[NUM_TOF]  = { 0x30, 0x31, 0x32 };

// --- Driver de Motores TB6612FNG ---
// Canal A (Motor 1)
#define MOTOR_AIN1_PIN  13  
#define MOTOR_AIN2_PIN  25
#define MOTOR_PWMA_PIN  18

// Canal B (Motor 2)
#define MOTOR_BIN1_PIN  14
#define MOTOR_BIN2_PIN  27
#define MOTOR_PWMB_PIN  19

// Ativação da Ponte H
#define MOTOR_STBY_PIN  5

// --- Encoders 
#define ENCODER_ESQ_PINA  32
#define ENCODER_ESQ_PINB  33

#define ENCODER_DIR_PINA  34
#define ENCODER_DIR_PINB  35

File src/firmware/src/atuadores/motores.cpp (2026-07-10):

#include <Arduino.h>
#include "motores.h"
#include "../config/pinos.h"

namespace {
constexpr uint32_t PWM_FREQ_HZ = 20000;
constexpr uint8_t PWM_RES_BITS = 8;
constexpr uint8_t PWM_MAX = 255;
constexpr uint8_t PWM_CANAL_ESQUERDO = 0;
constexpr uint8_t PWM_CANAL_DIREITO = 1;

constexpr uint8_t RAMPA_PASSO_PWM = 5;
constexpr uint16_t RAMPA_INTERVALO_MS = 10;

struct MotorConfig {
    uint8_t in1;
    uint8_t in2;
    uint8_t pwm;
    uint8_t canalPwm;
};

struct MotorEstado {
    int16_t velocidadeAtual;
    int16_t velocidadeAlvo;
};

const MotorConfig configs[NUM_MOTORES] = {
    { MOTOR_AIN1_PIN, MOTOR_AIN2_PIN, MOTOR_PWMA_PIN, PWM_CANAL_ESQUERDO },
    { MOTOR_BIN1_PIN, MOTOR_BIN2_PIN, MOTOR_PWMB_PIN, PWM_CANAL_DIREITO }
};

MotorEstado estados[NUM_MOTORES] = {
    { 0, 0 },
    { 0, 0 }
};

bool driverHabilitado = false;
uint32_t ultimoPassoRampaMs = 0;

// --- Estado do modo cruzeiro+correcao ---
bool    modoCruzeiro   = false;   // false = modo legado por-motor
int16_t cruzeiroAlvo   = 0;       // base desejada (rampeada)
int16_t cruzeiroAtual  = 0;       // base atual (após rampa)
int16_t correcaoAtual  = 0;       // diferencial imediato (não rampeado)

int16_t limitarVelocidade(int16_t velocidade) {
    if (velocidade > PWM_MAX) return PWM_MAX;
    if (velocidade < -PWM_MAX) return -PWM_MAX;
    return velocidade;
}

bool motorValido(MotorId motor) {
    return motor < NUM_MOTORES;
}

bool pwmAnexar(const MotorConfig& cfg) {
#if defined(ESP_ARDUINO_VERSION_MAJOR) && ESP_ARDUINO_VERSION_MAJOR >= 3
    return ledcAttach(cfg.pwm, PWM_FREQ_HZ, PWM_RES_BITS);
#else
    ledcSetup(cfg.canalPwm, PWM_FREQ_HZ, PWM_RES_BITS);
    ledcAttachPin(cfg.pwm, cfg.canalPwm);
    return true;
#endif
}

void pwmEscrever(const MotorConfig& cfg, uint8_t valor) {
#if defined(ESP_ARDUINO_VERSION_MAJOR) && ESP_ARDUINO_VERSION_MAJOR >= 3
    ledcWrite(cfg.pwm, valor);
#else
    ledcWrite(cfg.canalPwm, valor);
#endif
}

void aplicarSaida(MotorId motor, int16_t velocidade) {
    const MotorConfig& cfg = configs[motor];
    const uint8_t pwm = abs(velocidade);

    if (!driverHabilitado || velocidade == 0) {
        digitalWrite(cfg.in1, LOW);
        digitalWrite(cfg.in2, LOW);
        pwmEscrever(cfg, 0);
        return;
    }

    if (velocidade > 0) {
        digitalWrite(cfg.in1, HIGH);
        digitalWrite(cfg.in2, LOW);
    } else {
        digitalWrite(cfg.in1, LOW);
        digitalWrite(cfg.in2, HIGH);
    }

    pwmEscrever(cfg, pwm);
}

int16_t aproximar(int16_t atual, int16_t alvo) {
    if (atual < alvo) {
        atual += RAMPA_PASSO_PWM;
        return atual > alvo ? alvo : atual;
    }

    if (atual > alvo) {
        atual -= RAMPA_PASSO_PWM;
        return atual < alvo ? alvo : atual;
    }

    return atual;
}
}

bool motoresInit() {
    pinMode(MOTOR_STBY_PIN, OUTPUT);
    digitalWrite(MOTOR_STBY_PIN, LOW);

    for (uint8_t i = 0; i < NUM_MOTORES; i++) {
        pinMode(configs[i].in1, OUTPUT);
        pinMode(configs[i].in2, OUTPUT);

        if (!pwmAnexar(configs[i])) {
            Serial.printf("[Motores] ERRO: falha ao configurar PWM do motor %u\n", i);
            return false;
        }

        estados[i].velocidadeAtual = 0;
        estados[i].velocidadeAlvo = 0;
        aplicarSaida((MotorId)i, 0);
    }

    modoCruzeiro  = false;
    cruzeiroAlvo  = 0;
    cruzeiroAtual = 0;
    correcaoAtual = 0;

    motoresHabilitar(true);
    Serial.println("[Motores] TB6612FNG inicializado (PWM 20kHz, 8 bits)");
    return true;
}

void motoresAtualizar() {
    const uint32_t agora = millis();

    if (modoCruzeiro) {
        // A RAMPA atua SÓ na base (cruzeiro), a cada RAMPA_INTERVALO_MS.
        if (agora - ultimoPassoRampaMs >= RAMPA_INTERVALO_MS) {
            ultimoPassoRampaMs = agora;
            cruzeiroAtual = aproximar(cruzeiroAtual, cruzeiroAlvo);
        }

        // A CORRECAO é imediata (não passa pela rampa): aplicada todo ciclo.
        const int16_t vEsq = limitarVelocidade(cruzeiroAtual - correcaoAtual);
        const int16_t vDir = limitarVelocidade(cruzeiroAtual + correcaoAtual);

        // Espelha para leitura (motorLerVelocidadeAtual continua válido).
        estados[MOTOR_ESQUERDO].velocidadeAtual = vEsq;
        estados[MOTOR_DIREITO].velocidadeAtual  = vDir;

        aplicarSaida(MOTOR_ESQUERDO, vEsq);
        aplicarSaida(MOTOR_DIREITO,  vDir);
        return;
    }

    // --- Modo legado por-motor (comportamento original, inalterado) ---
    if (agora - ultimoPassoRampaMs < RAMPA_INTERVALO_MS) return;
    ultimoPassoRampaMs = agora;

    for (uint8_t i = 0; i < NUM_MOTORES; i++) {
        estados[i].velocidadeAtual = aproximar(estados[i].velocidadeAtual,
                                               estados[i].velocidadeAlvo);
        aplicarSaida((MotorId)i, estados[i].velocidadeAtual);
    }
}

void motoresHabilitar(bool habilitar) {
    driverHabilitado = habilitar;
    digitalWrite(MOTOR_STBY_PIN, habilitar ? HIGH : LOW);

    if (!habilitar) {
        for (uint8_t i = 0; i < NUM_MOTORES; i++) {
            estados[i].velocidadeAtual = 0;
            aplicarSaida((MotorId)i, 0);
        }
        cruzeiroAtual = 0;
        correcaoAtual = 0;
    }
}

// ----- Modo legado por-motor -----
void motorSetVelocidade(MotorId motor, int16_t velocidade) {
    if (!motorValido(motor)) return;
    modoCruzeiro = false;                         // sai do modo cruzeiro
    estados[motor].velocidadeAlvo = limitarVelocidade(velocidade);
}

void motorSetComando(MotorId motor, SentidoMotor sentido, uint8_t pwm) {
    if (!motorValido(motor)) return;

    if (sentido == MOTOR_PARADO || pwm == 0) {
        motorSetVelocidade(motor, 0);
        return;
    }

    const int16_t velocidade = (sentido == MOTOR_FRENTE) ? pwm : -((int16_t)pwm);
    motorSetVelocidade(motor, velocidade);
}

void motorParar(MotorId motor) {
    motorSetVelocidade(motor, 0);
}

// ----- Modo cruzeiro+correcao -----
void motoresSetCruzeiro(int16_t base) {
    modoCruzeiro = true;
    cruzeiroAlvo = limitarVelocidade(base);
}

// Arranca o cruzeiro DIRETO em 'base' (sem rampar do 0). Usado na saída da curva:
// com o cruzeiro em 0 na largada, a correção imediata do PID (ex.: completar o viés)
// jogaria uma roda pra trás -> giro no lugar. Arrancando em ~70, as duas rodas ficam
// pra frente e a correção vira uma curva suave (não "senta-e-pula").
void motoresIniciarCruzeiro(int16_t base) {
    modoCruzeiro  = true;
    cruzeiroAlvo  = limitarVelocidade(base);
    cruzeiroAtual = cruzeiroAlvo;   // pula a rampa 0->base
}

void motoresSetCorrecao(int16_t correcao) {
    modoCruzeiro = true;
    correcaoAtual = correcao;
}

// ----- Comum aos dois modos -----
void motoresParar() {
    cruzeiroAlvo  = 0;
    correcaoAtual = 0;
    for (uint8_t i = 0; i < NUM_MOTORES; i++) {
        estados[i].velocidadeAlvo = 0;
    }
}
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

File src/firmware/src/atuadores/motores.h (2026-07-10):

#pragma once

#include <stdint.h>

enum MotorId : uint8_t {
    MOTOR_ESQUERDO = 0,
    MOTOR_DIREITO  = 1,
    NUM_MOTORES    = 2
};

enum SentidoMotor : int8_t {
    MOTOR_RE       = -1,
    MOTOR_PARADO   = 0,
    MOTOR_FRENTE   = 1
};

bool motoresInit();
void motoresAtualizar();
void motoresHabilitar(bool habilitar);

// -----------------------------------------------------------------------------
// MODO LEGADO (por motor) — controle individual com RAMPA (slew-rate).
// Usado por teste_motores.cpp e, por enquanto, por navegacao.cpp.
// Chamar qualquer um destes coloca o driver de volta no modo por-motor.
// -----------------------------------------------------------------------------
void motorSetVelocidade(MotorId motor, int16_t velocidade);
void motorSetComando(MotorId motor, SentidoMotor sentido, uint8_t pwm);
void motorParar(MotorId motor);

// -----------------------------------------------------------------------------
// MODO CRUZEIRO+CORRECAO — para controle de rumo/curva.
//   - A BASE (cruzeiro) é rampeada suavemente (evita picos de corrente/derrapagem).
//   - A CORRECAO (diferencial) é aplicada IMEDIATAMENTE, sem rampa, para o PID
//     ter autoridade instantânea.
//   Saída final:  esquerdo = base - correcao ; direito = base + correcao.
// Chamar qualquer um destes ativa o modo cruzeiro.
// -----------------------------------------------------------------------------
void motoresSetCruzeiro(int16_t base);       // velocidade de avanço comum (rampeada)
void motoresIniciarCruzeiro(int16_t base);   // arranca o cruzeiro DIRETO em base (sem rampar do 0)
void motoresSetCorrecao(int16_t correcao);   // diferencial imediato (PID)

// Para ambos os modos: zera cruzeiro, correcao e alvos por-motor.
void motoresParar();

// Freio ATIVO (short-brake): curto-circuita os motores (as duas entradas do
// TB6612 em HIGH) pra parar seco, matando o rolamento livre. Persiste até o
// próximo comando de movimento. Use de preferência JÁ EM BAIXA velocidade.
void motoresFrear();

int16_t motorLerVelocidadeAtual(MotorId motor);  // saída aplicada AGORA (inclui rampa)
int16_t motorLerVelocidadeAlvo(MotorId motor);

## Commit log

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2026-04-25 docs(energia): especificações técnicas e cálculos de consumo
    - Identificação detalhada dos subsistemas elétricos (Motores, ESP32, Sensores).
    * Cálculo do consumo energético estimado por ciclo de operação (1897.78 J).
    * Especificação da bateria Lishen LR2170SA (2S1P) e justificativa de autonomia.
    - Definição da arquitetura de regulação (Buck DC-DC) e proteção (BMS 2S).
    * Inclusão de diretrizes de montagem (solda ponto) e telemetria (INA219).
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2026-04-25 Adicionado Lishen LR2170SA e o MPU6050
    Adicionado as especificações da bateria Lishen LR2170SA (21700), com “2 packs com duas baterias cada” e do MPU6050.
2026-04-28 EN_15: atualização dos componentes e pesos v1.2
    - Resolve #15
    - Atualização para a versão 1.2 do documento.
    - Inclusão do 4º sensor VL53L0X e da IMU MPU6050.
    - Ajuste do peso do pack para ~180g (conforme reunião de 24/04).
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2026-05-21 feat: configura barramento I2C e leitura de MPU6050 + VL53L0X (#71)
    Implementa a camada de perceção sensorial do Micromouse:
    - i2c_bus: inicialização do barramento e scan de diagnóstico
    - imu: wrapper do MPU6050 com leitura de giro Z (°/s) e calibração de offset
    - tof: inicialização sequencial de 3 VL53L0X via XSHUT com reatribuição
    de endereços únicos (0x30–0x32) para evitar conflito no barramento
    - main: firmware de teste que imprime giro Z + distâncias a 5 Hz via Serial
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2026-05-27 [FIX]Limpando arquivos de template e estruturando as páginas
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2026-05-27 fix: remove marcadores de conflito residuais do page.tsx
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2026-05-27 [FIX]:correção de tipo de arquivo
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2026-06-02 feat: refatora arquitetura do backend para padrao MSC, downgrade do Prisma para versao 5 e adiciona simulador mock do robo
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2026-06-06 Inicio da Integração e criação do mock de teste de estresse da api
2026-06-06 Adicionando mais duas apis para coletas dos dados específicos das corridas e suas determinadas telemetrias e continuação da integração
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2026-06-08 feat(tests): testes unitarios e CI automatizado - Issue 1
    - Configura Jest + ts-jest com cobertura minima de 80%
    - Testes unitarios do TelemetryService e TelemetryController
    - Testes de integracao HTTP via Supertest
    - Mock isolado do PrismaClient
    - Workflow CI no GitHub Actions
2026-06-16 [fix] arrumando o package-lock.json que eu tinha estragado
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2026-06-23 [REF] otimiza render do minimapa com Set de células visitadas (#97)
    Cada célula do grid varria a lista inteira de telemetrias (.some) para saber
    se foi visitada, dando O(células × telemetrias) por render. Agora as células
    visitadas são pré-computadas num Set (memoizado), tornando a checagem O(1) e
    o custo total O(células + telemetrias) — alívio em máquinas mais fracas.
2026-06-30 Adição dos CADs finais ao repositório
    [3D_PCB_2026-05-07.step, Abraçadeira impressa para os motores.SLDPRT, Assembly Final.SLDASM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]
2026-07-01 Fix: Ajuste do CAD e adição do modelo final do carro
    [Assembly Final.SLDASM, Chassi Final.SLDPRT]
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2026-07-03 test(backend): amplia cobertura de testes unitarios e integracao para getRuns, getRunById e getTelemetriesByRunId
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2026-07-03 test(frontend): configura Vitest e adiciona testes unitarios de componentes e contexto (99% cobertura)
2026-07-03 implementa um log para o pid do giro e reta no labirinto
    [teste_giro_1.csv, teste_giro_2.csv, teste_giro_3.csv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]
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2026-07-04 [ADD] frontend consome telemetria via WebSocket (backfill + reconexao)
    Substitui o polling HTTP do run-context por assinatura WebSocket, usando o
    canal que o backend da feat/web_socket ja expoe (ws://.../ws), sem alterar o
    backend:
    - ao acompanhar, abre o WebSocket e recebe cada telemetria por push;
    - ao ver uma corrida nova, faz backfill da trajetoria ja salva via REST
    (GET /runs/:id/telemetries) e depois segue anexando os pontos ao vivo;
    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
2026-07-04 [ADD] padroniza protocolo WebSocket com envelope { type, payload }
    O backend passa a falar em envelopes { type, payload } no WebSocket, em vez de
    trafegar o objeto cru:
    - novo modulo api/ws/protocol.ts (parseMensagem tolerante + envelope());
    - server.ts: despacha por type (telemetria -> salva e retransmite enveloped;
    ping -> pong) e ignora tipos desconhecidos;
    - leitura TOLERANTE: mensagem sem envelope e tratada como telemetria, para
    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
2026-07-04 [ADD] distingue papel robo/app no WebSocket (telemetria so p/ apps)
    Conexoes se identificam pela URL (?role=robo; default app):
    - parsePapel() deriva o papel da URL de conexao;
    - so os apps entram na lista de broadcast; a telemetria salva e retransmitida
    apenas aos apps (o robo nao recebe o proprio eco);
    - simulador conecta como ?role=robo.
    Testes do parsePapel (robo/app/default/invalido) — jest 80/80. Validado em
    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
2026-07-04 [REF] frontend le telemetria no envelope { type, payload }
    Ajusta o consumo do WebSocket para o protocolo do backend (PR do envelope):
    - onmessage desembrulha msg.payload quando ha type "telemetria";
    - ignora outros tipos (ex.: pong);
    - tolerante a objeto cru (payload ?? cru), caso chegue sem envelope.
    Testes atualizados para o envelope + casos de pong ignorado e objeto cru.
    Vitest: 75/75.
2026-07-04 fix(ws): alinhar simulador ao protocolo web socket
2026-07-04 [FIX] fixa turbopack.root no frontend para nao travar o next dev
    Sem turbopack.root, o Next infere a raiz do workspace como src/ (ha
    package-lock.json em backend/ e frontend/) e o dev server passa a vigiar a
    arvore inteira de src/ (~70k arquivos: backend/node_modules, firmware/.pio,
    etc.), estourando a memoria e derrubando o next dev em maquinas mais fracas.
    Fixando a raiz em src/frontend, o watcher passa a ver so os ~50 arquivos de
    fonte do frontend.
2026-07-04 [FIX] elimina flash do caminho anterior ao iniciar nova corrida
    O reset de estado (telemetria/telemetries/runIdAtual) acontecia dentro do
    useEffect, que so roda DEPOIS do React re-renderizar com corridaEmAndamento
    ja true. Isso deixava a tela mostrar por um frame o caminho da corrida
    anterior antes de limpar, causando o efeito visual de 'preenche e depois apaga'
    ao clicar em Iniciar Gravacao.
2026-07-05 valida os encoders novamente com o material do labirinto
    [teste_giro_1.csv, teste_giro_2.csv, teste_giro_3.csv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]
2026-07-05 valida os sensores tof e gera um script para identificar possíveis erros
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2026-07-06 [ADD] firmware envia telemetria por WebSocket (task no Core 0)
    - Robo conecta como cliente WebSocket (?role=robo) e transmite telemetria
    no envelope { type, payload } a ~5 Hz, alem de envio imediato ao entrar num
    estado terminal (para o backend finalizar a corrida na hora).
    - Task de telemetria FIXADA no Core 0 (junto do WiFi); a navegacao segue no
    loop() (Core 1). Estado compartilhado via snapshot protegido por mutex.
    - Leitura dos ToF acontece no Core 1 (dono do I2C); a task do Core 0 so le o
    snapshot ja capturado.
    - Send-only: sem canal de comando web->robo (RF01). bateria_pct e placeholder
    (sem INA219 neste firmware).
    - config/rede.h centraliza SSID/senha/host do backend.
    - tes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
    [main.cpp, telemetria.cpp, teste_ws.cpp]
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2026-07-07 [FIX] frontend deriva o host do backend em runtime (fim do localhost fixo)
    Substitui os enderecos hardcoded http://localhost:3000 por um helper
    (lib/backend.ts) que deriva o host a partir de window.location.hostname no
    navegador (e localhost no SSR). Assim o dashboard funciona tanto em
    http://localhost:3001 quanto acessado pelo IP da rede (ex.: de outro aparelho),
    sem apontar para 'localhost', que no outro dispositivo seria o proprio aparelho.
    Suporta override por NEXT_PUBLIC_BACKEND_HOST. Ajusta run-context (REST+WS),
    table-runs e a pagina de detalhe da corrida. 75/75 testes passando.
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2026-07-08 [FIX] atualiza fluxo websocket e documentação de testes
    [main.cpp, telemetria.cpp]
2026-07-10 [FIX] Atualização do mapa a cada célula
    [main.cpp, telemetria.cpp]
